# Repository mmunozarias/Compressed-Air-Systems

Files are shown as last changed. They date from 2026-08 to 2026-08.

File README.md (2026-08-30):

# Compressed-Air Systems

Work on compressed-air engines and their control, University of Groningen.

## CAE-bench

The compressed-air Wankel engine test bench: bill of materials, assembly,
wiring, calibration, firmware, control software and the 2024 measurement data.
Start at `CAE-bench/README.md`.

## compressed-air-ph-control

Port-Hamiltonian control of compressed-air engines. Simulation code for
"Energy-Based Speed Regulation of Compressed-Air Engines",
Munoz-Arias, Esquivel-Sancho and del Puerto-Flores.

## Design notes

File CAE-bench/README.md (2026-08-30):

# Compressed-Air Wankel Engine Test Bench

Everything needed to rebuild the compressed-air engine experiment used in
**Mechanical Craftsmanship & Design and Construction** at the Faculty of Science and
Engineering, University of Groningen.

A 3D-printed Wankel rotary engine runs on air from a converted fire-extinguisher
tank. A servo-driven ball valve throttles the inlet. Pressure, flow and shaft speed
are logged, and a PID loop regulates engine speed by commanding the valve.

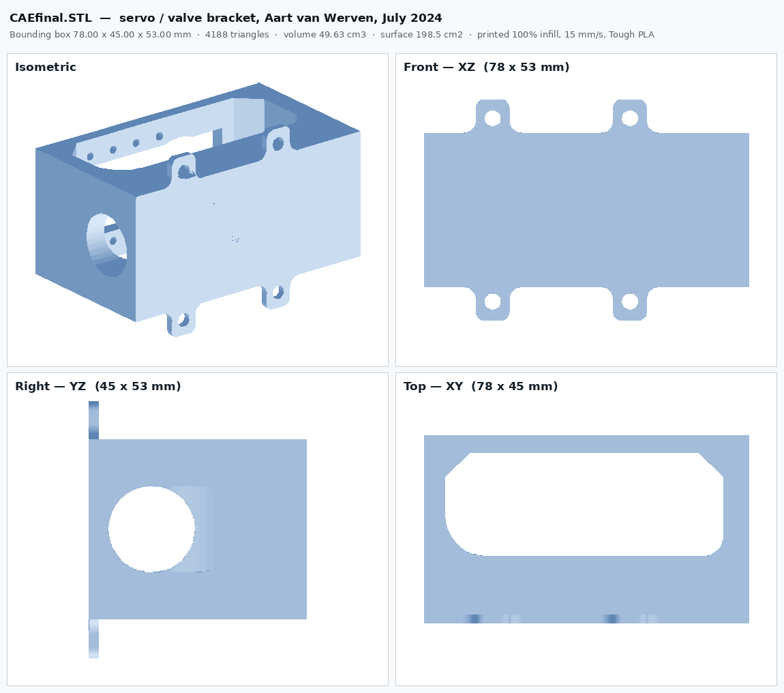
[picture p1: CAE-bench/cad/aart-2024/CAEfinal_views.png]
The servo and valve bracket


---

## Read this first

**The 2024 data in this repository is wrong by known, fixed factors.** Speed is a
factor of 4.84 too low and flow is 12.4 times too high, from a counting-window bug in
the acquisition chain. Corrected copies are in `data/processed/`, and the arithmetic
is in [`docs/07_KNOWN_ISSUES.md`](docs/07_KNOWN_ISSUES.md). **Fix defects D1 to D3
before you take a single new measurement.**

**Two gaps remain, and this repository says exactly where they are.** The three
student final reports and the original assembly-manual PDF are not here — download
links are in [`MISSING_FILES.md`](MISSING_FILES.md) §D. And five printed parts, all
of which carry an instrument, have no CAD in any archive and must be redrawn
([`MISSING_FILES.md`](MISSING_FILES.md) §E). Everything mechanical, pneumatic and
electrical that was ever drawn or flashed is in this repository.

---

## Contents

```
CAE-bench/
├── README.md                     you are here
├── MISSING_FILES.md              what to download, what to redraw, what is gone
├── CITATION.cff
├── docs/
│   ├── 01_BILL_OF_MATERIALS.md   pneumatic, mechanical, sensors, actuator, electrical
│   ├── 02_MECHANICAL_ASSEMBLY.md safety, engine build, frame, actuator, torque rig
│   ├── 03_PNEUMATIC_CIRCUIT.md   the air path, operating points, valve area curve
│   ├── 04_ELECTRONICS_AND_WIRING.md  pin map, Dynamixel chain, why 5 V
│   ├── 05_SENSORS_AND_CALIBRATION.md pressure, flow, force, speed resolution
│   ├── 06_SOFTWARE.md            install, run, control law, data format
│   └── 07_KNOWN_ISSUES.md        seven defects, the torque gap, two doc errors
├── cad/
│   ├── README.md                 measured geometry and the print profile
│   ├── aart-2024/                the servo and valve bracket (6 files)
│   ├── wankel-2023/              engine, covers, crank, shaft, pulleys (8 files)
│   │   └── Random/               design iterations and STEP exports (17 files)
│   ├── pneumatics/               sensor adapters and valve frame (5 files)
│   └── torquemeter/              the friction-brake torque rig (11 files)
├── firmware/
│   ├── arduinoADC/               the 2024 acquisition sketch
│   ├── legacy-2024/              the superseded January 2024 sketch
│   └── bench-2023/               calibration, brake and sensor-test sketches (11 files)
├── software/
│   ├── CAEPC.py                  the 2024 PC-side control loop
│   ├── requirements.txt
│   └── matlab/                   the 2023 MATLAB controller and dataset scripts
├── data/
│   ├── raw-2024/                 11 runs as logged, plus their PDF plots
│   └── processed/                the same runs with corrected columns
└── reference/
    ├── assembly_manual_2024.md
    ├── sensor_calibration_procedure_2023.md
    ├── MCDC_Sensor_calibration_procedure.pdf   the original of the above
    └── bench_purchase_record.csv
```

---

## Build it

1. **[Bill of materials](docs/01_BILL_OF_MATERIALS.md)** — order the parts. Budget
   about €300–350 plus €11 of filament for one bench. Two things to get right:
   the bearings are **R188 ZZ 6.35 × 12.7 × 4.76 mm** (the 3.18 mm version was
   superseded), and the bracket screws are **M4**, not the M2 the old report says.
2. **Print the parts.** `cad/wankel-2023/` for the engine, `cad/pneumatics/` for the
   sensor adapters, `cad/aart-2024/` for the servo bracket at 100 % infill, and
   `cad/torquemeter/` if you are building the brake. Redraw the five missing sensor
   mounts — `MISSING_FILES.md` §E lists them.
3. **[Assemble](docs/02_MECHANICAL_ASSEMBLY.md)** — engine first, and it must spin
   freely by hand before anything else is attached.
4. **[Plumb it](docs/03_PNEUMATIC_CIRCUIT.md)** — tank, adapter, pressure tee, flow
   sensor, hand valve, servo valve, engine. Leak-test at 2 bar before going to 8.
5. **[Wire it](docs/04_ELECTRONICS_AND_WIRING.md)** — pressure to A0, flow to D2,
   IR to D3. Those two digital pins are fixed by the Uno's interrupt hardware.
6. **[Calibrate](docs/05_SENSORS_AND_CALIBRATION.md)** — pressure, then flow, then
   force. Do not skip this; the shipped constants are for water.
7. **[Run it](docs/06_SOFTWARE.md)** — flash `arduinoADC.ino`, then
   `python CAEPC.py`. 60-second runs, step the hand valve open at t ≈ 10 s.

---

## Safety

The tank is a repurposed fire extinguisher. **8 bar maximum.** Eye protection
whenever it is charged. The engine reaches roughly 2700 rpm unloaded at the normal
operating point and over 7000 rpm in the high-pressure test; printed parts leaving a
rotor at that speed are dangerous. Aart van Werven's own closing note: *"running the
experiment at full force can not be considered safe, the screws in the current
connecting piece loosen due to the high vibrations and rotational force and get
launched at high speed."* Fit a guard and thread-lock the coupling screws.

---

## Provenance

Four student generations, one bench.

| Year | Who | Contribution |
|---|---|---|
| 2023 | **Koen Kiewiet** | 3D replication of the Wankel and multi-domain characterisation. BSc Integration Project. |
| 2023 | **Niek Hilbrands** | Closed-loop PID speed control and a Simscape digital twin. `Final_PID.m`, `Final_DT.slx`. |
| 2023 | **Jelmer Veenhuizen & Quentin Hopman** | Teaching assistants. The sensor calibration procedure, and the friction-brake torque rig that was never logged. |
| 2024 | **Damien Dufour** | The assembly manual and the engine technical drawings. |
| 2024 | **Aart van Werven** | Electronics rebuild: Raspberry Pi 5 + Arduino ADC, Dynamixel AX-12A, Python control loop, the servo bracket in `cad/aart-2024/`. All data in `data/raw-2024/`. |
| 2023–25 | **Max Kloosterman** | Teaching assistant and hardware custodian; later the pneumatic rover and the microscope valve-area characterisation. |

Supervised by **Mauricio Muñoz-Arias**, ENTEG, Faculty of Science and Engineering,
University of Groningen.

Upstream repository: `github.com/AartCodes/RUG-Pneumatic-Engine-experiment`
(the report cites the old username `Avuxy`).

---

## Contributing to this bench

The three things most worth doing next, in order:

1. **Fix the acquisition** (D1, D2, D4, D6). Timestamp the publish window instead of
   assuming it. This is about ten lines and it makes every future measurement valid.
2. **Wire the load cell.** The cells are bought and fitted, the friction brake is
   printed, the calibration procedure is written. One analog channel and a column in
   the Excel writer closes a gap that three student generations listed as future work.
3. **Reprint the interruptor disc with 10 lobes** instead of 3. Together with (1) this
   takes speed resolution from about 97 rpm to about 29 rpm.

A twenty-second coast-down run — spin up, close the valve, log until it stops — would
also give `b/J` for the shaft directly from the decay slope. No run in the archive
contains one, and it is the only shaft parameter measurable without a torque channel.

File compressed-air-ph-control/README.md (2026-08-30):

# Energy-Based Speed Regulation of Compressed-Air Engines

Simulation code for

> M. Munoz-Arias, L. M. Esquivel-Sancho and D. del Puerto-Flores,
> "Energy-Based Speed Regulation of Compressed-Air Engines,"
> *IEEE Transactions on Control Systems Technology* (submitted).

The scripts here regenerate **Figure 3** and **Figure 4** of the paper and print
every number quoted in Section V and Table II, so the results can be checked
without re-deriving anything.

---

## Contents

| File | What it does |
|---|---|
| `cae_model.py` | Shared parameters and dynamics, eqs. (6) to (35). Draws nothing. |
| `cae_open_loop.py` | Open-loop three-chamber simulation. Produces **Figure 3** and the Section V-A numbers. |
| `cae_closed_loop.py` | Closed-loop controller simulation, eqs. (40) to (42). Produces **Figure 4** and **Table II**. |
| `requirements.txt` | Python dependencies. |

Every function carries the equation number it implements. `cae_model.py` opens
with a table mapping each equation of the paper to the code that realises it.

Equation numbers in the source comments refer to the manuscript.

---

## Requirements

Python 3.9 or newer, with NumPy, SciPy and Matplotlib.

---

## Setup on Windows (PowerShell)

Check that Python is on the path:

```powershell
python --version
```

If that fails, install Python from <https://www.python.org/downloads/windows/>
and tick **Add python.exe to PATH** during installation.

Clone the repository and create a virtual environment inside it:

```powershell
git clone https://github.com/<user>/<repo>.git
cd <repo>
python -m venv .venv
```

Activate the environment:

```powershell
.\.venv\Scripts\Activate.ps1
```

If PowerShell refuses with a script-execution error, allow local scripts for
this session only and try again:

```powershell
Set-ExecutionPolicy -Scope Process -ExecutionPolicy Bypass
.\.venv\Scripts\Activate.ps1
```

Install the dependencies:

```powershell
python -m pip install --upgrade pip
python -m pip install -r requirements.txt
```

---

## Running

Both scripts write a vector `.pdf` for the paper and a `.png` preview into the
current directory, and print their results to the terminal.

```powershell
python cae_open_loop.py
python cae_closed_loop.py
```

Useful options:

```powershell
python cae_closed_loop.py --show              # open an interactive window
python cae_open_loop.py --outdir figures      # write into .\figures\
python cae_open_loop.py --tmax 30 --n 24000   # run length and sample count
```

To deactivate the environment when finished:

```powershell
deactivate
```

---

## What you should see

### `cae_closed_loop.py`

This reproduces Table II of the paper exactly. Expected output:

```
[baseline]  A=5.0  Kp=0.002  Kd=0.0005  Ki=0.002
   Delta(s), eq. (51) = s^3 + 10 s^2 + 65 s + 100
   eigenvalues of M   : -3.973-5.735j, -3.973+5.735j, -2.054+0j
   Routh a2a1 - a3a0  : 550.0   > 0, Hurwitz
   decay rate gamma   : 2.054 1/s

[fast]  A=12.0  Kp=0.008  Kd=0.0012  Ki=0.01
   Delta(s) = s^3 + 24 s^2 + 324 s + 1200
   eigenvalues of M   : -9.324-11.72j, -9.324+11.72j, -5.353+0j
   Routh a2a1 - a3a0  : 6576.0   > 0, Hurwitz
   decay rate gamma   : 5.353 1/s

[baseline] omega_e = 2000.1 rpm,  z = 0.0500 N m,  theta_bar = -3.69e-03 rad
[fast    ] omega_e = 2000.0 rpm,  z = 0.0500 N m,  theta_bar = -1.64e-09 rad
```

The script also checks that the eigenvalues of the closed-loop matrix `M` in
eq. (47) agree with the roots of the characteristic polynomial of eq. (49) to
machine precision, which is the numerical statement of Theorem 2.

### `cae_open_loop.py`

Four panels: tank pressure, chamber gauge pressure, pipe mass flow and shaft
speed, each for `D = 1.0` and `D = 0.5`. The engine self-starts, runs, and stops
when the tank reaches atmospheric pressure. The script prints the peak speed,
the plateau speed, the mean flow and the stopping time for each throttle
setting. Expected output:

```
D = 1.0 (fully open)
    peak shaft speed        2169.2 rpm
    plateau speed (2-5 s)    735.2 rpm
    mean flow (2-5 s)       2186.8 L/h
    engine stops at          10.13 s
D = 0.5 (half open)
    peak shaft speed        1940.8 rpm
    plateau speed (2-5 s)    750.9 rpm
    mean flow (2-5 s)       2172.7 L/h
    engine stops at          11.10 s
```

These are the numbers quoted in Section V-A. The figures the scripts write are
byte-for-byte the ones included in the manuscript.

---

## Model notes

**Geometry.** The simulations use the **measured** bench geometry,
`V_BAR = 8.25e-6` m^3 and `DELTA_V = 1.25e-5` m^3, not the reference geometry
of Table I, whose mean chamber volume of 0.1 L is about twelve times larger.
This is the scale discrepancy discussed in Section VII, and it accounts for
roughly an order of magnitude in the absolute pressure and flow amplitudes.

**Port timing.** The four port angles in `cae_model.py`
(`INTAKE_OPEN`, `INTAKE_CUTOFF`, `EXHAUST_OPEN`, `EXHAUST_CLOSE`) are not
documented for this engine and are set to physically reasonable values rather
than calibrated. The steady-speed plateau is sensitive to them. This is the
port-timing calibration gap named in Section VII, and closing it against a
measured bench trace is the first item of future work.

**Scope of the closed-loop result.** `cae_closed_loop.py` simulates the shaft
subsystem under Assumption 3, which is the setting Theorems 1 and 2 address. It
does not include the valve realisation, the one-sided throttling authority, or
the depleting tank. The commanded torque staying inside the engine envelope is
evidence that the realisability assumption is not being violated, but the full
cascade on the three-chamber plant is future work.

---

## Licence

%% TODO: choose a licence. MIT is the usual choice for code accompanying a
%% paper. Add a LICENSE file at the repository root.

## Citing

%% TODO: add the BibTeX entry for the paper once it has a DOI, and consider
%% archiving a release on Zenodo so the code itself is citable.

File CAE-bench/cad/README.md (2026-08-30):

# CAD

## What is here

`aart-2024/` — the servo and valve bracket, complete, byte-exact from Aart van
Werven's repository. This is the only subassembly whose CAD survived with its author.

| File | What |
|---|---|
| `CAEfinal.STL` | the bracket, mesh form, 4188 triangles |
| `CAE(1).SLDPRT` | SolidWorks source for the bracket |
| `CAEconnect.SLDPRT` | SolidWorks source for the servo horn |
| `UMS5_CAE8.3mf` | Cura 5.7.1 project, sliced, with the full print profile |
| `CAEfinal_views.png` | measured orthographic and isometric views |
| `UMS5_CAE8_thumbnail.png` | Cura's own render |

Both `.SLDPRT` files are post-2015 compressed SolidWorks containers. They open in
SolidWorks and nowhere else; there is no extractable preview or neutral geometry.
If you do not have SolidWorks, work from `CAEfinal.STL` and the measurements below.

## Measured geometry — CAEfinal.STL

Taken from the mesh, not from the report.

```
bounding box      78.00 x 45.00 x 53.00 mm
triangles         4188
volume            49.63 cm3 solid
surface area      198.46 cm2
mass in PLA       61.5 g at 100% infill, 1.24 g/cm3

valve bore        D 17.87 mm, axis along X
                  centre at Y 12.96, Z 26.46

mounting holes    4 x D 3.96 mm   <- M4 clearance, the report's "M2" is wrong
                  X 16.48 and 49.48   (33.00 mm apart)
                  Z  4.49 and 48.49   (44.00 mm apart)

top plate         carries the AX-12A screw pattern and the horn slot
horn screws       16 mm apart, into the AX-12A horn
```

## Print profile, recovered from the 3MF

Cura 5.7.1, UltiMaker S5, dual extrusion.

```
global            layer_height 0.2 · adhesion_type none · prime_tower True
                  support_enable True · support_structure tree
left  (AA 0.4)    Tough PLA Red · infill 100% · speed 15 mm/s · walls 5 · support infill 40%
right (BB 0.4)    PVA           · infill  70% · speed 50 mm/s · walls 5 · support infill 10%
print time        17 h 42
```

**The part is on the left extruder.** Table II of the 2024 report quotes the right
extruder's numbers (70 % / 50 mm/s), which describe the PVA support, not the part.
Print at 100 % infill; this bracket takes the servo reaction torque.

## What is not here

`wankel-2023/`, `pneumatics/` and `torquemeter/` are empty placeholders. Those files
are binary and could not be pulled programmatically. Every download link is in
`MISSING_FILES.md` section C.

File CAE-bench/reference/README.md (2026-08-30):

# Reference documents

Primary sources, transcribed. The originals are linked in `MISSING_FILES.md` §B and
§C6 — download them, because the drawings and figures do not survive transcription.

| File | Original | Author, date |
|---|---|---|
| `assembly_manual_2024.md` | `Compressed_air_engine_assembly_manual (4).pdf` | Damien Dufour, 6 Feb 2024 |
| `sensor_calibration_procedure_2023.md` | `MCDC_Sensor_calibration_procedure (1).pdf` | Jelmer Veenhuizen & Quentin Hopman, 6 Nov 2023 |
| `bench_purchase_record.csv` | `BoM_experimentalSetup_MCDC.xlsx` | MCDC teaching team, 2023-24 |

**The assembly manual contains technical drawings that are not reproduced here** —
dimensioned drawings for the Wankel mainframe, top cover and rotor, plus the full
piston and turbine engine variants. Download the PDF if you need them.

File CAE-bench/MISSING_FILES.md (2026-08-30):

# Files still to fetch, and files that no longer exist

Updated 30 August 2026, after the manual Drive download.

**The CAD and 2023 firmware gaps are closed.** Four of the five folders that were
empty are now populated: `cad/wankel-2023/`, `cad/pneumatics/`, `cad/torquemeter/`
and `firmware/bench-2023/`. What remains below is a short list.

---

## A. Byte-exact, in the repository

### A1. From `github.com/AartCodes/RUG-Pneumatic-Engine-experiment` @ `270cbc5`

- `firmware/arduinoADC/arduinoADC.ino`
- `firmware/legacy-2024/CEA_OLD_Jan_2024.ino`
- `software/CAEPC.py`, `software/matlab/baip_old.m`
- `cad/aart-2024/` — all four CAD files
- `data/raw-2024/` — all 11 run workbooks and their PDF plots
- `CITATION.cff`

### A2. Downloaded by hand from Google Drive, 30 August 2026

| Folder | Count | Contents |
|---|---|---|
| `cad/wankel-2023/` | 8 + 17 | Engine assembly, mainframe, top cover, rotor, crank, output shaft, two GT2 pulleys; `Random/` holds the design iterations and STEP exports |
| `cad/pneumatics/` | 5 | Sensor adapters, flow-valve frame and adapter |
| `cad/torquemeter/` | 11 | **The complete friction-brake torque rig** — bases, three brake rotors, two friction elements, holder, coupling stabiliser, engine mounting base, and the Cura 3MF |
| `firmware/bench-2023/` | 11 | Calibration sketches, three brake firmwares, the demo sketch, sensor test sketches (three non-firmware files were refiled — §B2) |

---

## B. Three files that arrived and were not on any list

Worth knowing about — none of these appeared in the original sweep.

| File | Where it landed | Why it matters |
|---|---|---|
| `Final_PID.m` | now `software/matlab/` | **The byte-exact original** of the 2023 controller. The repository previously held only the text-recovered copy. Verified — see §B1. |
| `NewDatasetPQN.m` | now `software/matlab/` | A MATLAB pressure/flow/speed dataset script that accompanied the January 2024 demo. Not referenced in any report. |
| `braccioServoTestwithoutShield.ino`, `pressure_sensor.ino`, `water_flow_sensor.ino` | `firmware/bench-2023/` | Single-sensor test sketches. The two sensor ones are the cleanest reference for the raw pin reads. |

### B1. The diff was run, and it passed

`software/matlab/Final_PID_2023_RECOVERED.m` was reconstructed from a
markdown-escaped API rendering. On 30 August 2026 it was compared line by line
against the original. **No numeric literal and no operator differs.** `Kp`, `Ki`,
`Kd`, `desiredRPM`, the event-based `RPM = 60/elapsedTime`, the `(flow/11)*60`
scaling and the `min(45, Angle)` clamp are all identical.

The only differences were whitespace, a provenance header added during recovery, one
comment shortened, and one typo in Hilbrands' comments silently corrected
(`%Filering` to `% Filtering`). Every conclusion in `docs/07_KNOWN_ISSUES.md` that
was drawn from the recovered file therefore holds against the original.

The recovered copy has been deleted. `software/matlab/Final_PID.m` is the original.

### B2. Three misfiled files were moved — done

They arrived inside the firmware zip but are not firmware. All three are now in place:

| File | Now at |
|---|---|
| `MCDC_Sensor_calibration_procedure.pdf` | `reference/` — the byte-exact original of `reference/sensor_calibration_procedure_2023.md` |
| `Final_PID.m` | `software/matlab/` |
| `NewDatasetPQN.m` | `software/matlab/` |

---

## C. Recovered as text, and therefore NOT byte-exact

The Google Drive API returns text files as a markdown-escaped rendering. These were
mechanically un-escaped. Two of the four now have their originals in the repository.

| File in this repo | Original | Status |
|---|---|---|
| `software/matlab/Final_PID_2023_RECOVERED.m` | — | **Verified against the original, then deleted. See §B1.** |
| `reference/sensor_calibration_procedure_2023.md` | `reference/MCDC_Sensor_calibration_procedure.pdf` | Original PDF is in the repository |
| `reference/assembly_manual_2024.md` | https://drive.google.com/file/d/12QYhJ9bgo3Mi30Q98cJiB5EE-rjmYTcK/view | still text-only, **unverified** |
| `reference/bench_purchase_record.csv` | https://drive.google.com/file/d/12S-FDaBVhX_Im-J83x53LmS7h7cCgfUk/view | still text-only, **unverified** |

---

## D. Still to download

Short list. Everything else on the old list arrived.

### D1. One STL, one adapter

| File | Into | Link | Note |
|---|---|---|---|
| `crank rotary_full_thread.STL` | `cad/wankel-2023/` | https://drive.google.com/file/d/1MkxhRA-5ii5pRoACFyRBst1Ptty3XrNf/view | `crank rotary_full_thread.STEP` and `…1.SLDPRT` did arrive, in `Random/`. Only the print-ready mesh is absent. |
| `g78p14_to_g18p28_ASPART.STL` | `cad/pneumatics/` | Drive folder "Adaptors & Connectors" | G7/8-1/4 to G1/8-1/4 thread adapter |

### D2. Two firmware variants

| File | Into | Link |
|---|---|---|
| `calibration_pressureNEW.ino` | `firmware/bench-2023/` | https://drive.google.com/file/d/10WHNEVndiqODSPl31ZAOfcYgzPOO-sFT/view |
| `Cal_flow1.ino` | `firmware/bench-2023/` | https://drive.google.com/file/d/1XcnWjRBtoMcRpctCfh-zhMIp4V-T_4Xi/view |

Both are variants of sketches that already arrived. Low priority.

### D3. Reference documents, into `reference/`

The largest remaining gap, and the one that matters most for a stranger trying to
rebuild the bench — the three final reports contain the reasoning behind the design.

| File | Link |
|---|---|
| `Compressed_air_engine_assembly_manual (4).pdf` — with all technical drawings | https://drive.google.com/file/d/12QYhJ9bgo3Mi30Q98cJiB5EE-rjmYTcK/view |
| `BoM_experimentalSetup_MCDC.xlsx` | https://drive.google.com/file/d/12S-FDaBVhX_Im-J83x53LmS7h7cCgfUk/view |
| `Final report - Aart van Werven.pdf` | https://drive.google.com/file/d/1jeOsAo6GKKWHYmRFczAijTgDJKLy9ffv/view |
| `Koen Kiewiet - Final Report.pdf` | https://drive.google.com/file/d/19jPMe1Uf--jlzvOY9KKocOAmeYLkY6l5/view |
| `Niek Hilbrands - Final Report.pdf` | https://drive.google.com/file/d/19nG8YkGtTjL5F2W3YVkus5UZwvXdnWn0/view |
| `CAE_drawing3.pdf`, `CAE.SLDPRT`, `CAE.SLDDRW` — **the dimensioned 2D drawing** | Gmail, 6 May 2024, message `18f4c5735a05912d` |
| Purchase orders, ~90 PDFs | https://drive.google.com/drive/folders/15pth04qXh3LmkRtO3BiwIH30W6IG_41J |

Check the licence position on the student reports before pushing them to a public
repository.

---

## E. Does not exist anywhere — must be redrawn

Five printed parts appear in the bill of materials with no CAD in any archive,
including the folders downloaded on 30 August 2026. All five carry an instrument.

| Part | Qty | What it does |
|---|---|---|
| **IR-sensor interruptor disc** | 1 | 3-lobe disc on the output shaft. **Redraw with 10 lobes** — see `docs/07_KNOWN_ISSUES.md` D1. |
| **IR-sensor holder** | 1 | positions the photo interrupter over the disc |
| **Load-cell attachment** | 2 | mounts the load cell to the brake arm. Without it the torque channel cannot be rebuilt. |
| **Sensor holder** | 1 | holds the pressure and flow sensors to the plank |
| **Tube holder** | 4 | routes the 8 mm line |

The load-cell attachment is now the **only** thing standing between this bench and a
working torque channel. Every other part of the rig — the brake, the rotors, the
friction elements, the coupling, and `calibration_force.ino` — is in this repository.

---

## F. Corrupt

`Engine_mount_wankel.STL` appears twice in the shared drive at **zero bytes**, ids
`1t633eYdxz7QXZYz_nJCpnm2AZ7vxKtjh` and `13ULi0r8Ysf9A_df54gEAvZRMN9DEu9cy`. Both
copies are unrecoverable. Use `cad/torquemeter/Engine mounting base.stl` instead —
it is now in the repository.

`cad/wankel-2023/Random/rotorstepje.err` is a SolidWorks export error log, not a
model. It is kept because it records a failed STEP translation of the rotor.

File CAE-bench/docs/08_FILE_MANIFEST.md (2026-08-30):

# 8 — File manifest

Every file in this repository, where it came from, and how much to trust it.

Legend — **A** byte-exact from Aart's GitHub repository · **B** recovered as text
through the Drive API and mechanically un-escaped, verify before relying on it ·
**C** generated during the August 2026 audit · **E** downloaded by hand from Google
Drive on 30 August 2026, byte-exact · **D** placeholder, download still required.

| Path | Src | Bytes | What it is |
|---|---|---|---|
| `README.md` | C | — | Entry point |
| `MISSING_FILES.md` | C | — | Download list, redraw list, corrupt list |
| `CITATION.cff` | A | 700 | Aart's citation metadata |
| **docs/** | | | |
| `01_BILL_OF_MATERIALS.md` | C | — | Merged from the TA bench BOM and Aart's Appendix A |
| `02_MECHANICAL_ASSEMBLY.md` | C | — | From the 2024 assembly manual plus the CAD measurements |
| `03_PNEUMATIC_CIRCUIT.md` | C | — | Air path, operating points, valve area curve |
| `04_ELECTRONICS_AND_WIRING.md` | C | — | Pin map read out of the firmware |
| `05_SENSORS_AND_CALIBRATION.md` | C | — | From the Veenhuizen & Hopman procedure |
| `06_SOFTWARE.md` | C | — | Install, run, control law, data format |
| `07_KNOWN_ISSUES.md` | C | — | Seven defects, the torque gap, two doc errors |
| `08_FILE_MANIFEST.md` | C | — | This file |
| **cad/aart-2024/** | | | |
| `CAEfinal.STL` | A | 209 484 | Servo/valve bracket, 4188 triangles |
| `CAE(1).SLDPRT` | A | 338 482 | SolidWorks source, bracket |
| `CAEconnect.SLDPRT` | A | 98 441 | SolidWorks source, servo horn |
| `UMS5_CAE8.3mf` | A | 196 921 | Cura 5.7.1 project with the full print profile |
| `CAEfinal_views.png` | C | 37 899 | Measured orthographic and isometric views |
| `UMS5_CAE8_thumbnail.png` | C | 29 731 | Extracted from the 3MF |
| `README.md` | C | — | Measured geometry and print settings |
| **cad/wankel-2023/** | E | — | 8 files: `Wankel assembly.SLDASM`, mainframe, top cover, `rotor.step.SLDPRT`, `crank rotary.SLDPRT`, `outputshaft wankel redesigned.stl`, two GT2 pulleys |
| `cad/wankel-2023/Random/` | E | — | 17 files: Casing/Lid/Rotor/Shaft 1-8 iterations, STEP exports, `crank rotary_full_thread`, `rotorstepje.err` |
| **cad/pneumatics/** | E | — | 5 files: two sensor adapters, tube-to-flow-sensor connector, `frame_flowvalve.stl`, `frame_updated.stl` (use this one) |
| **cad/torquemeter/** | E | — | 11 files: the complete friction brake. `Engine mounting base.stl` replaces the corrupt `Engine_mount_wankel.STL` |
| **firmware/** | | | |
| `arduinoADC/arduinoADC.ino` | A | 3 100 | 2024 acquisition sketch. JSON over serial at 19200 |
| `legacy-2024/CEA_OLD_Jan_2024.ino` | A | — | The superseded January 2024 sketch |
| `bench-2023/torquemotor1–3.ino` | E | — | The three brake firmwares. Never used in any report |
| `bench-2023/calibration codes/` | E | — | `calibration_pressure`, `calibration_flow`, **`calibration_force`** — the load-cell sketch |
| `reference/MCDC_Sensor_calibration_procedure.pdf` | E | 167 479 | The original calibration procedure, Veenhuizen & Hopman |
| `bench-2023/CEA_Demo_22_Jan_2024/` | E | — | The January 2024 live-demo sketch |
| `bench-2023/pressure_sensor/`, `water_flow_sensor/`, `flow_pressure_combined/`, `braccioServoTestwithoutShield/` | E | — | Single-sensor and servo test sketches |
| **software/** | | | |
| `CAEPC.py` | A | 14 056 | 2024 PC-side control loop, Dynamixel + matplotlib + xlsx |
| `requirements.txt` | C | — | Reconstructed from the imports; not in the original repo |
| `matlab/baip_old.m` | A | 8 600 | Marked outdated in the original repository |
| `matlab/Final_PID.m` | E | 8 539 | Hilbrands' 2023 controller, byte-exact original. The recovered copy was verified against it and deleted — MISSING_FILES.md §B1 |
| `matlab/NewDatasetPQN.m` | E | 6 052 | Pressure/flow/speed dataset script, January 2024 demo |
| **data/raw-2024/** | | | |
| `DATACAE.xlsx` … `ResultNoPID2.xlsx` (11 files) | A | ~40 kB each | The runs as logged. **Speed ×4.84 too low, flow ×12.4 too high.** |
| `*.pdf` (10 files) | A | — | The plots as generated at run time |
| `experiment_data.pdf` | A | — | Combined plot export |
| **data/processed/** | | | |
| `CAE_bench_corrected_data.xlsx` | C | — | All 11 runs with corrected columns, driven by formula from one correction sheet |
| **reference/** | | | |
| `assembly_manual_2024.md` | **B** | — | Dufour, 6 Feb 2024. Technical drawings NOT reproduced |
| `sensor_calibration_procedure_2023.md` | **B** | — | Veenhuizen & Hopman, 6 Nov 2023 |
| `bench_purchase_record.csv` | **B** | — | The compressed-air rows of the MCDC purchase record |
| `README.md` | C | — | Source table for the above |

## Verifying the B files

```powershell
# after downloading the original from the link in MISSING_FILES.md
git diff --no-index original.m software/matlab/Final_PID_2023_RECOVERED.m
```

Expect differences in whitespace and in the header comment block, which was added.
Any difference in a numeric literal or an operator is a transcription error — fix it
and note it here.

## Suggested .gitignore

```
__pycache__/
*.pyc
.venv/
*.tmp
~$*
```

Everything else in this tree is meant to be committed, including the data.

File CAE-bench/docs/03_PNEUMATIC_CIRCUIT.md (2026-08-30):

# 3 — Pneumatic circuit

## 3.1 The line, in order

```
  [ Fire extinguisher tank, 8 bar max ]
              |
              |  G7/8-14 outlet
        ( P2 ) printed adapter  g78p14_to_g18p28_ASPART.STL   -> G1/8
              |
        ( P4 ) PC8-01 straight fitting, 1/8 BSP -> 8 mm push-fit
              |
        ( P3 ) 8 mm OD / 5 mm ID PU hose
              |
        ( P6 ) G1/8 T-split ----------------> ( S2 ) PRESSURE SENSOR
              |                                     G1/4, 0-100 psi, analog
              |
        ( S1 ) FLOW SENSOR, SENSTREE G1/2
              |    via printed adapters S5
              |
        ( P8 ) HAND BALL VALVE   <- master isolation, operator controlled
              |
        ( P9 ) SERVO BALL VALVE  <- THE CONTROL ELEMENT, driven by the AX-12A
              |                     mounted in CAEfinal.STL
              |
        [ WANKEL ENGINE inlet port ]
              |
        exhaust to atmosphere
              |
      output shaft --> ( S3 ) IR PHOTO INTERRUPTER (speed)
                   --> optional brake + load cell (torque)
```

## 3.2 Notes that are easy to get wrong

**The pressure sensor reads line pressure, not tank pressure.** In the 2024 data the
open-loop runs peak at only 2.4-2.6 bar while the closed-loop runs reach 6.1-7.4 bar,
from the same tank charge. That is the pressure drop across the flow sensor and tubing
at high flow. If you want true tank pressure, tee the sensor in *before* the flow
sensor, or fit a second transducer.

**Keep the bends out of the 8 mm line.** The bracket was designed to raise the tube
height by only 1 mm precisely to avoid this. Every bend costs flow.

**Seal the printed adapters with O-rings, not tape.** The O-ring set (P10) was bought
for this. PTFE tape on a printed thread tends to shred.

**Leak test before every session.** Aart's predecessors lost measurement days to
leaks. Soap water at 2 bar, then work up.

## 3.3 Operating points on record

| Condition | Tank / line pressure | Speed (corrected) | Flow (corrected) |
|---|---|---|---|
| Open loop, valve wide | 2.4-2.6 bar at the sensor | 2655-3038 rpm plateau | ~2540-2700 L/h |
| Closed loop, setpoint 200 logged | 5.0-5.3 bar at the sensor | ~960 rpm | ~250-475 L/h |
| High-pressure limit test | 10.1 bar peak | up to ~7700 rpm peak | ~4700 L/h peak |

All speeds and flows above are **corrected** figures. The raw logs are wrong by fixed
factors; see `docs/06_KNOWN_ISSUES.md` before using any number from `data/raw-2024/`.

## 3.4 Valve angle and flow area

The throttle is a quarter-turn ball valve. Its flow area is **not** linear in angle:
it is the overlap of two circular apertures. Max Kloosterman measured a valve of the
same family through a microscope in 2 .5 degree steps:

| Rotation from fully open | Aperture, % of maximum |
|---|---|
| 0 deg | 100 % |
| 10 deg | 79 % |
| 20 deg | 57 % |
| 30 deg | 33 % |
| **40 deg** | **17 %** |
| **50 deg** | **5.7 %** |
| 55 deg | 1.5 % |

The pure two-circle geometry over-predicts badly (46 % where the real valve is 3 %
open). The empirical fit that works is the lens area multiplied by (1 - theta/60 deg).

**Consequence for control:** the 2024 bench settles at 43-44 degrees from open, which
is about **13 % of maximum aperture** — on the steep part of the curve, with almost no
margin before the engine stalls. Any controller for this rig should command *area*,
not angle, and invert this curve. That is what the 2025 rover firmware does.

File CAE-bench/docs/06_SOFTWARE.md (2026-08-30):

# 6 — Software

Two generations. Build the 2024 one; the 2023 MATLAB is included because it is
correct in ways the 2024 rewrite is not.

---

## 6.1 What runs where

| Layer | 2023 | 2024 (this repo) |
|---|---|---|
| Sensor acquisition | `CEA_OLD_Jan_2024.ino` on an Arduino Uno | `arduinoADC.ino` on an Arduino Uno |
| Wire format | CSV over serial, 19200 baud | **JSON lines** over serial, 19200 baud |
| Control loop | MATLAB, `Final_PID.m` | Python, `CAEPC.py` |
| Actuator | SpringRC SR431 via Arduino | Dynamixel AX-12A via U2D2 from the PC |
| Output | live MATLAB plots | live matplotlib + PDF + `.xlsx` |

---

## 6.2 Install

```powershell
# 1. Python 3.9 or newer, and the Arduino IDE
python --version

# 2. Python packages
python -m pip install -r software/requirements.txt

# 3. Flash the Arduino
#    Open firmware/arduinoADC/arduinoADC.ino in the Arduino IDE.
#    Install the ArduinoJson library via Library Manager.
#    Select Arduino Uno, pick the port, Upload.

# 4. Find your COM ports
#    Device Manager for the Arduino; Dynamixel Wizard for the servo.
#    Then edit software/CAEPC.py:
#        DEVICENAME = 'COM8'      <- the U2D2
#        ser = serial.Serial('COM6', 19200, timeout=0.1)   <- the Arduino
```

`software/requirements.txt` is reconstructed from the imports in `CAEPC.py`; it was
not in the original repository.

---

## 6.3 Run

```powershell
cd software
python CAEPC.py
```

The loop runs for **60 seconds** and then stops itself. It writes two files to your
Desktop:

- `experiment_data.pdf` — the four plots plus a text page of the raw arrays
- `DATACAE.xlsx` — columns `Time (s)`, `RPM`, `Pressure (Bar)`, `Flow Rate (L/m)`,
  `Servo Position`

Rename `DATACAE.xlsx` immediately after each run or the next run overwrites it. This
is how the 11 files in `data/raw-2024/` came to have ad-hoc names.

**Procedure for a run.** Start the script with the hand valve closed. At about
t = 10 s open the hand valve — this is the step input. The controller takes roughly
6 s to settle. Let it run to 60 s.

---

## 6.4 The control law as shipped

```python
class PID:
    def compute(self, setpoint, pv):
        error = setpoint - pv
        self.integral += error
        derivative = error - self.previous_error
        output = self.Kp*error + self.Ki*self.integral + self.Kd*derivative
        self.previous_error = error
        return output

pid = PID(0.1, 0.02, 0.0003)
Desired_Speed = 210          # was 200 for every run in data/raw-2024

servo_position = 200 + ((512 - 200) * pid_output / Desired_Speed)
```

Four things to know before you tune it. All four are expanded in
`docs/07_KNOWN_ISSUES.md`.

1. There is **no timestep** in the integral or derivative. The gains are per-sample,
   so they change if the loop rate changes.
2. There is **no anti-windup**. `set_servo_position` clamps to 200-512 while the
   integral keeps accumulating.
3. **The setpoint divides the actuator gain.** Loop gain at a setpoint of 100 is
   double that at 200 and four times that at 400. Retuning per setpoint is treating a
   symptom.
4. The **derivative term is inert** — with 20-unit speed quantisation and
   Kd = 0.0003 it contributes 0.006 servo units against a 0.5-unit deadband. This is
   a PI controller.

---

## 6.5 The 2023 MATLAB controller

`software/matlab/Final_PID_2023_RECOVERED.m`. Gains `Kp = -0.003`, `Ki = 0.0002`,
`Kd = -0.003`, setpoint **1500 rpm**, angle clamped to **0-45 degrees**.

Two things it does better than the 2024 rewrite:

- **Speed is event-based and correct.** It times one full revolution with `tic`/`toc`
  and computes `RPM = 60/elapsedTime`. No window assumption, no scale error.
- **Flow is labelled L/hour**, which matches the arithmetic.

It also does outlier rejection with a 10-sample moving mean on speed, pressure and
flow, which the Python rewrite dropped.

`software/matlab/baip_old.m` is the earlier MATLAB the repository marks as outdated.

---

## 6.6 Data format

`data/raw-2024/*.xlsx`, 11 runs, ~284 rows each:

| Column | Unit as labelled | Trust it? |
|---|---|---|
| `Time (s)` | s | Frame time, not sample time. Up to 3 samples share one stamp. |
| `RPM` | rpm | **No — multiply by 4.84** |
| `Pressure (Bar)` | bar absolute | Yes |
| `Flow Rate (L/m)` | L/min | **No — divide by 12.4 for L/min** |
| `Servo Position` | Dynamixel units, 200-512 | Yes |

`data/processed/CAE_bench_corrected_data.xlsx` has every run with corrected columns
driven by formula off a single correction sheet, so editing the measured emission rate
rescales the whole workbook.

Run-to-test mapping, verified by reproducing the report's own error metric:

| File | Setpoint | Role |
|---|---|---|
| `Result31` | 200 | Test 1 |
| `Result32` | 200 | Test 2 |
| `Result33` | 200 | Test 3 |
| `Result34` | 200 | Test 4 |
| `Result11` | 200 | Test 5 |
| `ResultNoPID`, `ResultNoPID2` | 200 | open-loop baselines |
| `Result10bar` | 200 | high-pressure limit test |
| `Result100` | 100 | low-setpoint test |
| `Result400` | 400 | high-setpoint test |
| `DATACAE` | 200 | unreported spare |

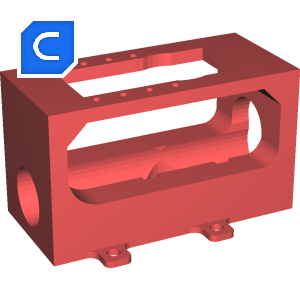
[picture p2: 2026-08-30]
CAE-bench/cad/aart-2024/UMS5_CAE8_thumbnail.png

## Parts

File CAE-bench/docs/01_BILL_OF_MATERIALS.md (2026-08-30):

# 1 — Bill of materials

Everything needed to build one compressed-air Wankel engine test bench, split by
discipline. Two sources are merged here: the **TA bench BOM** from
`BoM_experimentalSetup_MCDC.xlsx` (the setup as actually built, with quantities and
unit costs) and **Appendix A of Aart van Werven's 2024 report** (the setup after the
electronics rebuild). Where they disagree, both are shown.

Prices are as paid, 2023–24, in EUR unless the source quoted USD.

---

## 1.1 Pneumatic parts

| # | Part | Spec | Qty | Unit | Notes |
|---|---|---|-----|---|---|
| P1 | Air tank | Smartwares 10.014.68 ABC powder fire extinguisher, 2 kg — tank only, contents removed | 1 | €36.99 | This is the "pneumatic battery". A 1 kg version (10.018.56, €29.00) was also used. Maximum working pressure 8 bar in this application. |
| P2 | Tank outlet adapter | 3D printed, G7/8-14 to G1/8-28 | 1 | printed | `g78p14_to_g18p28_ASPART.STL`. Threads onto the extinguisher valve body. |
| P3 | Pneumatic tubing | HUAZIZ PU hose, 8 mm OD / 5 mm ID, blue | ~70 cm | €15.66 / 12 m | 10–12 m rolls were bought; a bench needs under a metre. |
| P4 | Straight push-fit fittings | TAILONZ PC8-01, 8 mm tube OD × 1/8 BSP male | 6–10 | €9.99 / 10 | The workhorse fitting of the whole rig. |
| P5 | Elbow push-fit fittings | TAILONZ male elbow, 8 mm OD × 1/8 BSP | 2–4 | €13.49 | For routing around the plank. |
| P6 | T-split | G1/8 pneumatic T-piece, or IQS R1/4 to 8 mm tee | 1 | €38.72 / set | Splits the line to the pressure sensor. |
| P7 | Quick connectors | 8 mm to 1/4 BSP adapters | 2 | €9.99 / 10 | Compressor side. |
| P8 | Hand shut-off valve | TAILONZ BVU-8, 8 mm OD ball valve, push-to-connect | 1 | €18.99 | Master isolation. Always fit one. |
| P9 | **Throttle valve (the actuator)** | TAILONZ BVU-8 8 mm OD ball valve — a second unit, driven by the servo | 1 | €9.99 | This is the control element. See §1.5 and `docs/03_PNEUMATIC_CIRCUIT.md`. |
| P10 | O-ring set | NBR, 32 sizes, 419 pieces | 1 set | €17.45 | Sealing the printed adapters. Sizes 1 and 2 in the TA BOM, ×2 and ×4. |
| P11 | Compressor | HBM, with 5-piece air tool set for the hose and couplings | 1 | €26.90 (accessories) | Any 8 bar workshop compressor. |

> **Safety.** The tank is a repurposed fire extinguisher. Do not exceed **8 bar**.
> Wear eye protection whenever the tank is charged. See §1 of the assembly manual
> in `reference/`.

---

## 1.2 Mechanical parts — the engine

The Wankel is fully 3D printed apart from bearings and fasteners.

| # | Part | Spec | Qty | Source |
|---|---|---|-----|---|
| M1 | Base cover / mainframe | PLA, printed | 1 | `Wankel mainframe.stl` |
| M2 | Top cover | PLA, printed | 1 | `Wankel topcover.stl` |
| M3 | Rotor | PLA, printed | 1 | `rotor.step.SLDPRT` |
| M4 | Crank / eccentric shaft | PLA, printed | 1 | `crank rotary.SLDPRT`, or `crank rotary_full_thread.STL` |
| M5 | Output shaft | PLA, printed | 1 | `outputshaft wankel redesigned.stl` |
| M6 | Bearing A — small | **IBB R188 ZZ, 6.35 × 12.7 × 4.76 mm** | 2 | Lagerkoning.nl, €82.45 / pack |
| M7 | Bearing B — large | IBB 6802 / 61802 2RS, 15 × 24 × 5 mm | 1 | Lagerkoning.nl, €32.28 |
| M8 | Apex seals | Graphite stick, 15 mm lengths, filed flush | 3 | STAEDTLER Mars Micro 1.3 mm HB, €7.67 |
| M9 | Super glue | any cyanoacrylate | 1 | €11.99 / 18 |
| M10 | Cover screws | **M3 × 12** | 6 | with M3 square nuts |
| M11 | Cover nuts | M3 DIN557 square nuts, SS304 | 6 | €6.10 / 100 |

> **Bearing substitution, February 2024.** The original spec was IBB R188
> 6.35 × 12.7 × **3.18** mm. It was replaced by **R188 ZZ 6.35 × 12.7 × 4.76 mm**.
> The 4.76 mm width is what is on the bench now. Ordering the 3.18 mm part will not fit.

---

## 1.3 Mechanical parts — the bench frame

| # | Part | Spec | Qty | Unit |
|---|---|---|-----|---|
| F1 | Base plank | wood, 30 × 40 cm | 1 | €5.25 |
| F2 | Corner bracket | Alberts 330330, heavy, zinc | 1 | €15.13 |
| F3 | M5 threaded rod | for the load arm / mounting | 1 | €5.48 |
| F4 | M5 nuts | Jeboler DIN 985 nylon-insert lock nuts, A2 | 2 | €12.52 / 100 |
| F5 | Wood screws | 3 × 12 T10 | 19 | €7.79 / 200 |
| F6 | Bracket mounting screws | **M4** — see the warning below | 4 | — |
| F7 | 5 mm bearing | for the output shaft support | 2 | €9.56 / 20 |
| F8 | Flexible shaft coupling | OKFLEX | 1 | €24.15 |
| F9 | Tank holder | supplied with the extinguisher | 1 | included |
| F10 | Arduino holder | supplied with the board | 1 | included |
| F11 | Tube holders | printed | 4 | **no CAD survives** |

> **M4, not M2.** Aart's report §IV-D-1 says the servo bracket is secured with
> "4 4-m2-screws". The holes in `CAEfinal.STL` measure **Ø3.96 mm**, which is M4
> clearance. Buy M4.

---

## 1.4 Sensors

| # | Sensor | Spec | Qty | Unit | Interface |
|---|---|---|-----|---|---|
| S1 | Flow | **SENSTREE G1/2 brass water flow sensor** | 1 | €16.11 | Digital pulse, 5 V. Pulse-per-litre constant 11 for water (see the calibration note). |
| S2 | Pressure | **G1/4 pressure transducer, 5 V in, 0.5–4.5 V out, 0–100 psi** | 1 | €19.07 | Analog. |
| S3 | Speed | **SHARP GP1A57HRJ00F photo interrupter** + SparkFun breakout | 1 | €16.85 + €5.85 | Digital, interrupt-driven. |
| S4 | Torque / force | **Load cell 500 g** (B0CJ93Y21V, €18.33) and **1 kg** (HALJIA, €7.99 ×2), plus a 100 g unit (€10.60) | 1–2 | — | Needs an **HX711** amplifier (ICQUANZX, €6.99). *Bought and fitted; never wired into the data acquisition. See `docs/06_KNOWN_ISSUES.md`.* |
| S5 | Sensor adapters | printed: G1/4-to-flowsensor, flow/pressure-to-G1/4 | 1 each | printed | `adapter pneumatic flow pressure sensor v2.stl`, `connector tube to flow sensor 1_8 v1.stl` |
| S6 | Sensor holder, IR holder, IR interruptor disc | printed | 1 each | printed | **no CAD survives — must be redesigned** |

> **The flow sensor is a water turbine used on air.** Its 11 pulses/litre constant
> does not transfer to a compressible fluid. Treat all flow readings as indicative
> until the sensor is calibrated against a known air flow. The 2023 team calibrated
> it by the choked-flow method; see `docs/04_SENSORS_AND_CALIBRATION.md`.

---

## 1.5 Actuator

Two generations exist. Build the 2024 one.

| Generation | Servo | Stall torque | Notes |
|---|---|---|---|
| 2023 | SpringRC **SR431** (from the Braccio arm kit) | 1.22 N·m @ 4.8 V, 1.45 N·m @ 6.0 V | Imprecise, vibrates at high flow, prone to failure. Replaced. |
| **2024 (build this)** | **DYNAMIXEL AX-12A** | **1.5 N·m @ 12 V** | €19.07. TTL protocol 1, ID 0, baud 1 000 000. |

The AX-12A needs three more items, all Reichelt:

| # | Part | Unit |
|---|---|---|
| A1 | DYNAMIXEL **U2D2** USB-to-TTL interface | €56.62 |
| A2 | **U2S2 PHB** Dynamixel U2D2 Power Hub | €40.62 |
| A3 | **SMPS 12 V 5 A** Dynamixel power adapter | €46.72 |

Plus two printed parts: the **valve + motor holder** (`CAEfinal.STL`) and the **horn**
that couples the servo output to the valve stem (`CAEconnect.SLDPRT`), screwed into
the AX-12A horn at two holes 16 mm apart.

---

## 1.6 Electrical and control

| # | Part | Spec | Qty | Unit |
|---|---|---|-----|---|
| E1 | Microcontroller | **Arduino Uno Rev 3** | 1 | €26.50 |
| E2 | Host computer | Any Windows/Linux PC. A **Raspberry Pi 5** was used in 2024 but Aart's own conclusion is that it "proved to be unnecessary, since the same functionality is achieved by running the code on a laptop or PC". | 1 | — |
| E3 | Breadboard | AZDelivery mini, 400 pin | 1 | €3.99 |
| E4 | Jumper wires | male/female sets, flexible | 1 set | €16.20 |
| E5 | Crimping tool + Dupont connectors | Homca SN-28B, 2030 connectors | 1 | €38.99 |
| E6 | 9 V battery clip to 2.1 mm DC jack | for standalone power | 1 | €10.75 |
| E7 | HX711 load-cell amplifier | ICQUANZX breakout | 1 | €6.99 |
| E8 | PVC insulation tape | | 1 | — |

---

## 1.7 Consumables and tooling

| Item | Spec |
|---|---|
| Filament, part | **UltiMaker Tough PLA, red** |
| Filament, support | **UltiMaker PVA** (water soluble) |
| Printer | UltiMaker S5 (S3 / S7 also used), AA 0.4 and BB 0.4 cores |
| Sandpaper | 120 grit, for the piston and turbine variants |
| Magnetic bit holder | 60 mm, 1/4" |
| Graphite | see M8 |

---

## 1.8 Complete printed-part list

| Part | Qty | CAD available? | File |
|---|-----|---|---|
| Wankel housing / mainframe | 1 (4 printed per cohort) | yes | `Wankel mainframe.stl` |
| Wankel top cover | 1 | yes | `Wankel topcover.stl` |
| Rotor | 1 | yes | `rotor.step.SLDPRT` + 8 iterations |
| Crank / eccentric | 1 | yes | `crank rotary.SLDPRT` |
| Output shaft | 1 | yes | `outputshaft wankel redesigned.stl` |
| Wankel frame | 1 | yes | `mainframe_wankel.step` |
| Valve + motor holder | 1 | **yes, in this repo** | `cad/aart-2024/CAEfinal.STL` |
| Servo horn / coupler | 1 | **yes, in this repo** | `cad/aart-2024/CAEconnect.SLDPRT` |
| Fire extinguisher adapter | 1 | probable | `g78p14_to_g18p28_ASPART.STL` |
| G1/4 to flow-sensor adapter | 1 | probable | `adapter pneumatic flow pressure sensor v2.stl` |
| Flow/pressure sensor to G1/4 | 1 | probable | `connector tube to flow sensor 1_8 v1.stl` |
| Throttle valve frame | 1 | yes | `frame_updated.stl` (supersedes `frame_flowvalve.stl`) |
| Throttle valve adapter | 1 | yes | `adapter_flowvalve.stl` |
| **Tube holder** | 4 | **NO** | — |
| **Sensor holder** | 1 | **NO** | — |
| **IR-sensor holder** | 1 | **NO** | — |
| **IR-sensor interruptor disc** | 1 | **NO** | — |
| **Load-cell attachment** | 2 | **NO** | — |
| Torquemeter base plate | 1 | yes | `Torquemotor base complete.stl` |
| Torquemeter clutch | 2 | yes | `friction part 11mm.stl`, `friction thingy 11.2mm.stl` |
| Torque meter holder | 1 | yes | `holder friction torquemotor.stl` |
| Brake rotor | 1 | yes | `Rotor Torquemotor 35mm.stl` or the 32 mm variant |
| Output shaft stabiliser | 1 | yes | `coupling output shaft stabilizer.stl` |
| Engine mounting base | 1 | yes | `Engine mounting base.stl` |

**Five printed part types have no CAD in any archive.** All five carry an
instrument. They are the tube holder, sensor holder, IR-sensor holder, IR
interruptor disc and load-cell attachment. See `MISSING_FILES.md`.

---

## 1.9 Approximate cost of one bench

Taking one of each item at the unit prices above and amortising the pack purchases,
a single bench is roughly **€300–350** in bought parts, plus about €11 of filament.
The dominant costs are the Dynamixel chain (U2D2 + U2S2 + SMPS + AX-12A ≈ €163) and
the sensors (≈ €60). The 2023 SpringRC generation was far cheaper but is the reason
the servo was replaced.

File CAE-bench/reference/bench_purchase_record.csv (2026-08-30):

category | part | supplier | description_on_invoice | qty_or_pack | cost_eur | notes
tank | Fire extinguisher 2 kg | Amazon.nl | Smartwares 10.014.68 Brandblusser poeder 2 kg ABC rood | 1 | 27.29 | Tank used as the pneumatic battery for the experimental setup
tank | Fire extinguisher 1 kg | Amazon.nl | Smartwares 10.018.56 (BB1) Brandblusser Poeder 1 kg ABC | 1 | 29.00 | Tank for the experimental setup and the rover
tank | Fire extinguisher foam 2 L | Amazon.nl | Smartwares SW SB2 SB2 Brandblusser Schuim 2 liter AB | 3 | 71.97 | First set converted to ballast configuration
tank | Fire extinguisher foam 2 L | Amazon.nl | Smartwares SW SB2 SB2 Brandblusser Schuim 2 liter AB | 2 | 47.98 | Second set converted to ballast configuration
tank | Fire extinguisher 1 kg ABC | IFSS B.V. via bol.com | ANAF Group Brandblusser 1 kg Poederblusser ABC | 5 | 114.75 | Final artifact tanks
tank | Fire extinguisher 1 kg ABC | IFSS B.V. via bol.com | ANAF Group Brandblusser 1 kg Poederblusser ABC | 6 | 137.70 | Pressure vessels for design cycle 2 rovers
pneumatic | Elbow fitting 8mm x 1/8 BSP | Amazon.nl | TAILONZ PNEUMATIC Mannelijke Elleboog 8mm Buis OD x 1/8 BSP Push | pack | 13.49 | 90 degree fittings
pneumatic | Straight fitting PC8-01 | Amazon.nl | TAILONZ PNEUMATIC Mannelijke Rechte 8mm Buis OD x 1/8 BSP Push | 10 | 9.99 | First set
pneumatic | Straight fitting PC8-01 | Amazon.nl | TAILONZ PNEUMATIC Male Straight 8mm Tube OD x 1/8 BSP PC8-01 | 10 | 9.99 | Second set
pneumatic | Straight fitting PC8-01 | Amazon.nl | TAILONZ PNEUMATIC Mannelijke Rechte 8mm Buis OD x 1/8 BSP | 10 | 9.99 | Third set
pneumatic | Straight fitting | Amazon.nl | Bwintech 12 Pcs 8mm Buis OD x 1/8 Mannelijke BSP Draad Rechte Push | 12 | 11.49 | Better delivery time than the first ones
pneumatic | Straight fitting | Amazon.nl | Bwintech 12 Pcs 8mm Buis OD x 1/8 Mannelijke BSP Draad Rechte Push in | 12 | 20.48 | Design cycle 2
pneumatic | Quick connector adapter | Amazon.nl | 10 stks Pneumatische Quick Connector Air Fittings Adapter 8mm 1/4BSP | 10 | 12.72 | Fourth set of fittings
pneumatic | Quick connector adapter | Amazon.nl | 10 stks Pneumatische Quick Connector Air Fittings Adapter 8mm | 10 | 6.44
pneumatic | T-piece | CNCTEC UG via Amazon | Pneumatische meervoudige steekschroefverbinding TE 1/4 - 8mm IQS T-stuk perslucht | set | 38.72 | Second set of pneumatic valves/fittings
pneumatic | Ball valve BVU-8 | Amazon.nl | TAILONZ PNEUMATIC 8mm OD Kogelklep Luchtstroom Regelklep Push | 1 | 18.99
pneumatic | Ball valve BVU-8 | Amazon.nl | TAILONZ PNEUMATIC 8mm OD Kogelklep Luchtstroom Regelklep Push | 2 | 37.98
pneumatic | Ball valve BVU-8 | Amazon.nl | TAILONZ PNEUMATIC 8mm OD Ball Valve Air Flow Control Valve BVU-8 | 5 | 75.96 | First set of pneumatic valves
pneumatic | Ball valve | Amazon.nl | ERGAOBOY 5 Pcs 8mm OD Pneumatische Kogelkraan | 5 | 18.99 | Used on the rovers
pneumatic | PU hose 8mm OD 5mm ID | Amazon.nl | HUAZIZ 8mm OD 5mm ID Pneumatic Air Hose PU Hose 12m Blue | 12 m | 29.98
pneumatic | PU hose 8mm OD | Amazon.nl | TAILONZ PNEUMATIC Blauw 8mm OD 10 Meter PU de Pijpslang | 10 m | 15.99
pneumatic | Splitters | Amazon.nl | TAILONZ PNEUMATIC 8mm OD Push to Connect Fittings Pneumatische | pack | 17.99 | Distributing air between cylinders
pneumatic | O-ring set | Bol.com | O-ringset 32 maten 419 delig NBR Rubber | 419 | 17.45 | Sealing the pneumatic system
pneumatic | Compressor accessories | Lemato | HBM 5 Delig Luchtgereedschapset | 1 | 26.90 | Hose and accessories for the HBM compressor
sensor | Flow sensor | Amazon.nl | SENSTREE G1/2 Mannelijke Draad Messing Water Flow Sensor | 1 | 16.11 | Water turbine sensor used on air
sensor | Flow sensor | Amazon.nl | SENSTREE G1/2 Mannelijke Draad Messing Water Flow Sensor | 1 | 16.11 | Second unit
sensor | Pressure sensor G1/4 | Amazon.nl | Druksensor G1/4 Drukomvormer Sensor Ingang 5V Uitgang 0.5-4.5V | pack | 57.21 | 0-100 psi
sensor | Photo interrupter | Vanallesenmeer.nl | GP1A57HRJ00F Photo Interrupter | 1 | 16.85 | Measures engine output velocity
sensor | Photo interrupter breakout | Vanallesenmeer.nl | Photo Interrupter Breakout Board | 1 | 5.85 | SparkFun
sensor | Photo interrupter | Vanallesenmeer.nl | GP1A57HRJ00F Photo Interrupter | pack | 49.50 | Additional units
sensor | Photo interrupter set | Vanallesenmeer.nl | GP1A57HRJ00F Photo Interrupter and Breakout Board SparkFun | pack | 51.30 | Closing the control loop
sensor | Load cell 500 g | Amazon.nl | Gewicht Sensor Silver 500g and hx711 B0CJ93Y21V | 1 | 18.33 | Measuring engine torque indirectly
sensor | Load cell 1 kg | Amazon.nl | HALJIA Draagbare elektronische gewichtssensor laadcel weegsensor 1KG | 1 | 7.99 | First item
sensor | Load cell 1 kg | Amazon.nl | HALJIA Draagbare elektronische gewichtssensor laadcel weegsensor 1KG | 1 | 7.99 | Second item
sensor | Load cell 1 kg | Amazon.nl | HALJIA Draagbare elektronische gewichtssensor laadcel weegsensor | pack | 15.98
sensor | Load cell 100 g | Amazon.nl | 0-100g zeer nauwkeurige digitale parallelle straal elektronische | 1 | 10.60 | Measuring engine torque indirectly
sensor | HX711 amplifier | Amazon.nl | ICQUANZX HX711 ADC converter breakout module digitale weegcel 1KG | 1 | 6.99 | Load cell amplifier
mechanical | Bearing 6802 2RS | Lagerkoning.nl | IBB Kogellager 6802/61802 2RS 15x24x5mm | pack | 32.28 | Bearing B in the Wankel
mechanical | Bearing R188 | Lagerkoning.nl | IBB Miniatuur Kogellager R188 6.35x12.7x3.18mm | pack | 32.28 | SUPERSEDED - see R188 ZZ
mechanical | Bearing R188 ZZ | Lagerkoning.nl | IBB Miniatuur Kogellager R188 ZZ 6.35x12.7x4.76mm | pack | 82.45 | Bearing A - THIS IS THE ONE IN USE
mechanical | Bearing R188 ZZ | Lagerkoning.nl | IBB Miniatuur Kogellager R188 ZZ | 4 | 11.95 | Design cycle 2
mechanical | Bearing 6802-2RS | Amazon.nl | 10 stuks groefkogellagers 6802-2RS 15x24x5mm | 10 | 13.30
mechanical | Bearing 6802-2RS | Amazon.nl | 6802-2RS bearings | 10 | 8.50 | Wankel engines design cycle 2
mechanical | Flexible shaft coupling | Okaphone | OKFLEX Flexibele as Koppeling | 1 | 24.15 | Improved engine mounting
mechanical | Corner bracket | Amazon.nl | Alberts 330330 Hoekanker extra sterk met rib sendzimir verzinkt | pack | 54.48
mechanical | M5 lock nuts | Amazon.nl | Jeboler M5 moeren 100 stuks zelfborgende A2 V2A 304 DIN 985 | 100 | 12.52
mechanical | M3 square nuts | Amazon.nl | 100 stuks M3 DIN557 metrische draad vierkante moeren SS304 | 100 | 6.10 | Wankel top cover
mechanical | Graphite | Amazon.nl | STAEDTLER Mars Micro Carbon 250 1.3mm HB Potlood Vullingen | pack | 7.67 | Apex seals and lubrication
mechanical | Graphite sticks | sostrene grenes | Graphite sticks | pack | 1.24 | Sealant for the Wankel
mechanical | Super glue | Amazon.nl | Orzanne 18 x secondelijm extra sterk alleslijm snellijm 100 g | 18 | 11.99
mechanical | Wood and screws | Hornbach | Wood screws and other materials | - | 72.25 | Wood planks o-rings and other items for the setup
electrical | Arduino Uno | - | Arduino UNO | 1 | 26.50 | From the TA bench BOM
electrical | Breadboard | AZDelivery | AZDelivery Mini Breadboard 400 Pin met 4 Busbars | pack | 15.96 | Rapid prototyping of the sensor wiring
electrical | Crimping tool | Amazon.nl | Homca SN-28B Krimptang 0.14-1 mm2 met 2030 Dupont-krimpconnectoren | 1 | 38.99 | Custom cables and connectors
electrical | Jumper wires and tape | Okaphone | PVC isolatietape Set Draadbruggen Male/Female Set soepele draadbruggen | set | 16.20 | Completing the setup wiring
electrical | 9V clip to DC jack | Kiwi Electronics | 9V Batterij clip naar 2.1mm DC plug | 1 | 10.75 | Standalone power
electrical | Cable adapter | Michele Chiapello | kabeladapter 9 V CLIP DC 2.1 JACK | 1 | 7.48
tooling | Magnetic bit holder | Daw21onlineshop | Magnetische bithouder 60mm lang 1/4 bit houder | 1 | 6.65 | Workshop tool
tooling | 3D printer nozzles | Amazon.nl | 24 pcs 0.2/0.3/0.4/0.5/0.6/0.8/1.0mm Messing MK8 3D Printer Nozzles | 24 | 10.99 | Used to regulate air flow in the turbine engine
tooling | Ultimaker limit switches | Makerpoint | Ultimaker Limit Switches | pack | 50.61 | Repair kit for the Ultimaker printers
misc | Magnets | Supermagnete.nl | Supermagneten used as payloads for the compressed-air engines | pack | 33.20 | Part of the load for the experimental setup
misc | Hardware bundle | Amazon.nl | Several hardware for the compressed air engines | - | 466.98 | Combined invoice

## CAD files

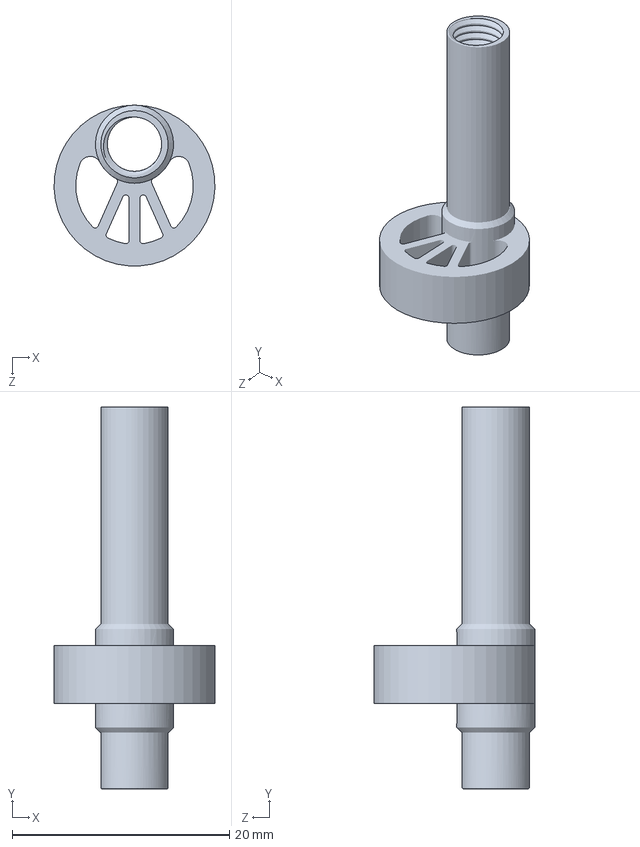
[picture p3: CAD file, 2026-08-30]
CAE-bench/cad/wankel-2023/Random/crank rotary_full_thread1.SLDPRT
14.8 x 35.2 x 14.8 mm

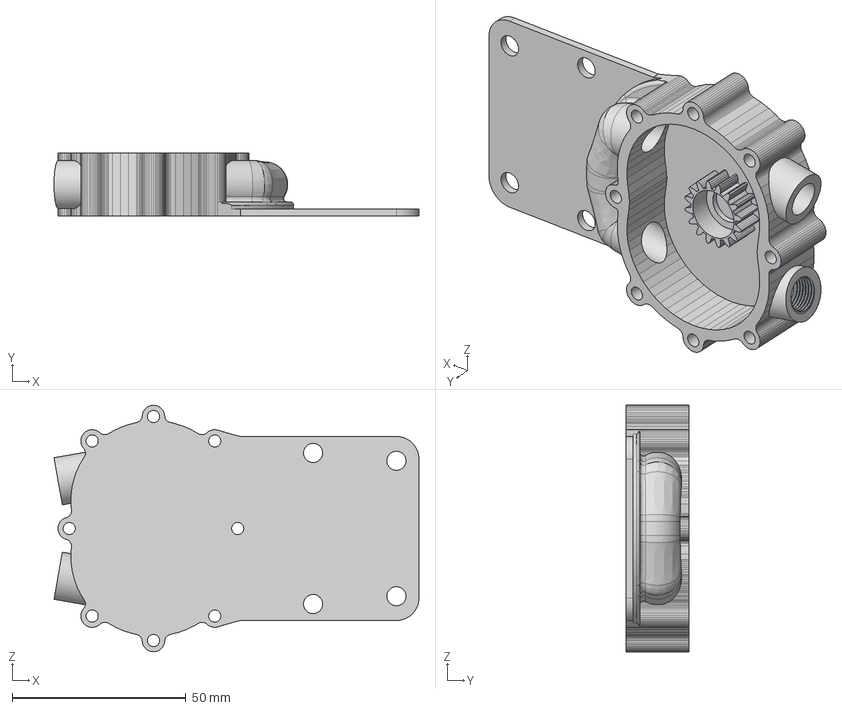
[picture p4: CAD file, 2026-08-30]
CAE-bench/cad/wankel-2023/Random/mainframe_wankel.step
105.1 x 18.0 x 71.0 mm

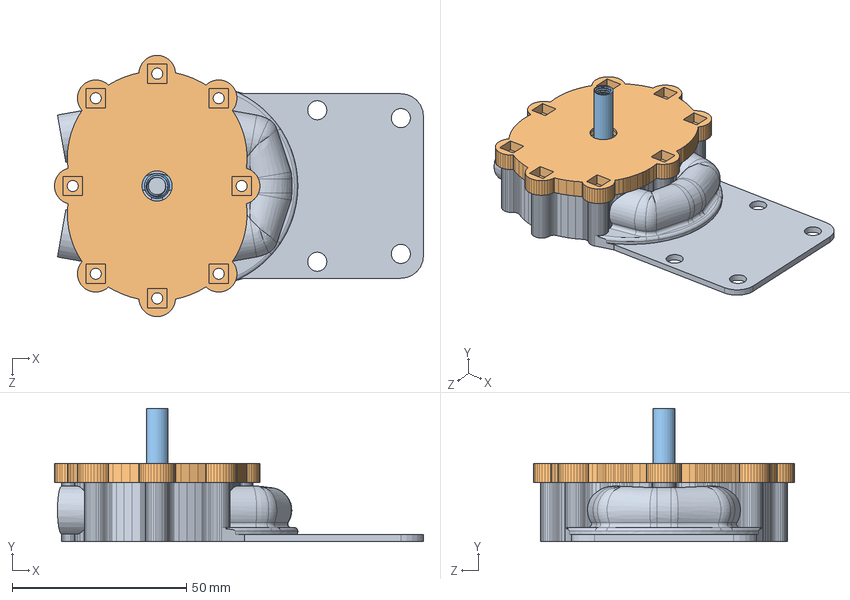
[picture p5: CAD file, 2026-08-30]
CAE-bench/cad/wankel-2023/Wankel assembly.SLDASM
105.9 x 38.2 x 75.0 mm
mainframe_wankel.step
Topcover_wankel.step
crank rotary
rotor.step

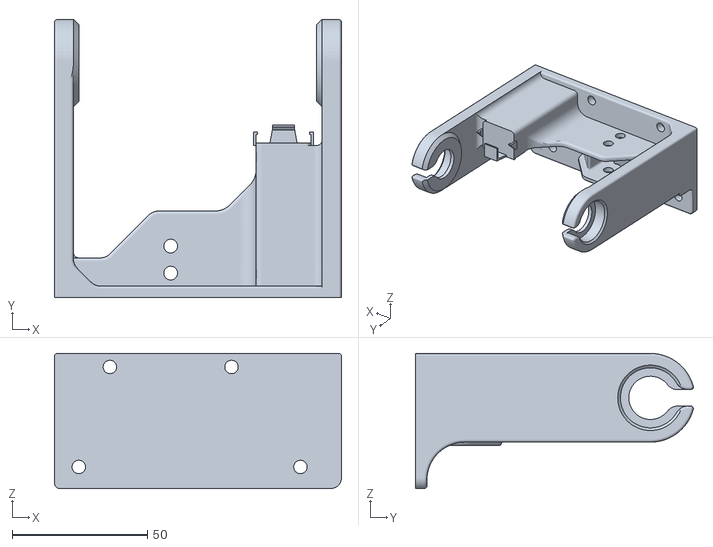
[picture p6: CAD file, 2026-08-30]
CAE-bench/cad/torquemeter/Torquemotor base complete.stl
106.2 x 102.8 x 50.0

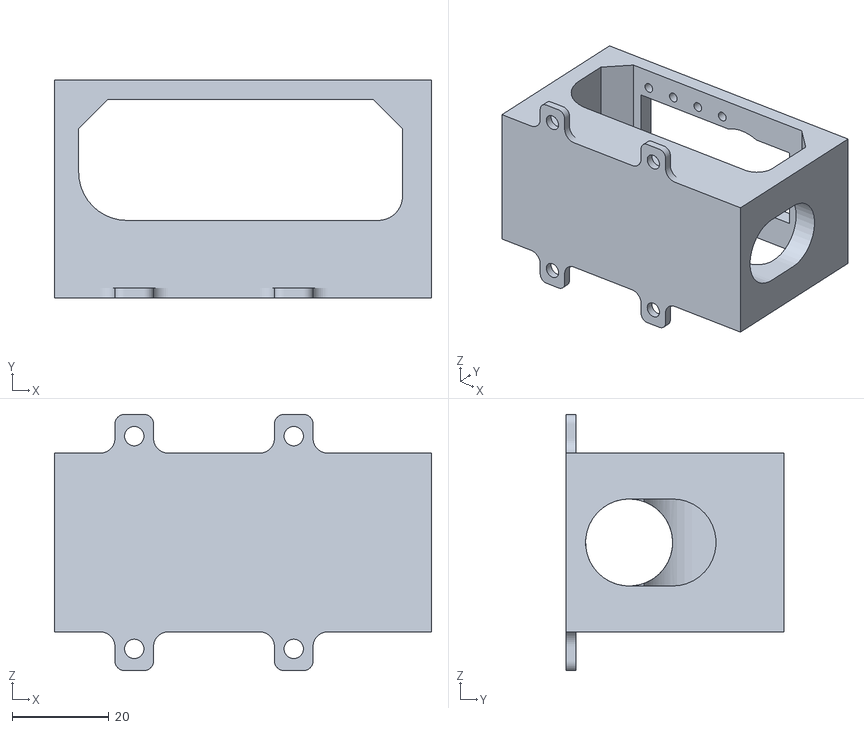
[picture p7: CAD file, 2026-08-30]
CAE-bench/cad/aart-2024/CAEfinal.STL
78.0 x 45.0 x 53.0

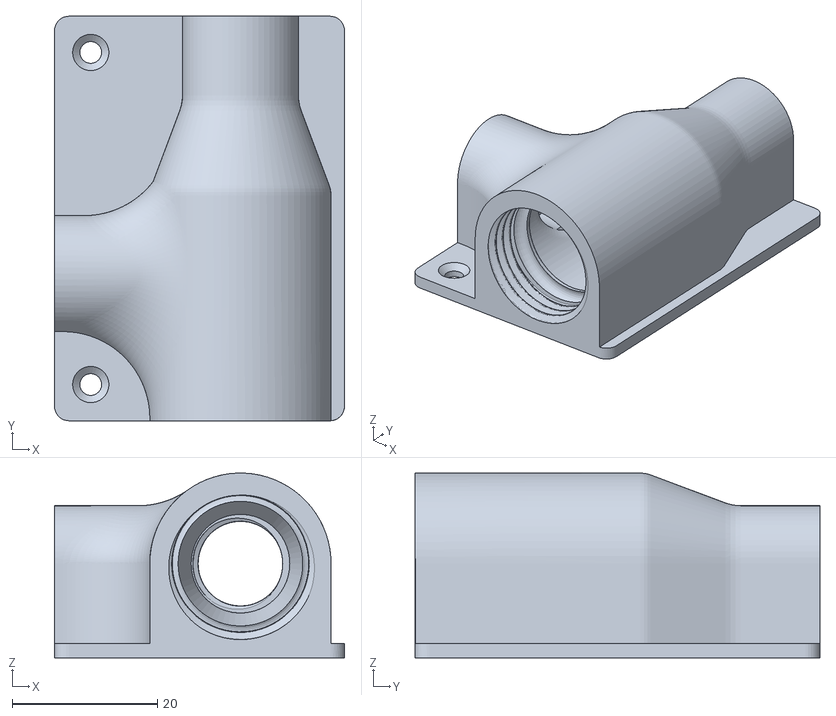
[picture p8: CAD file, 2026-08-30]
CAE-bench/cad/pneumatics/adapter pneumatic flow pressure sensor v2.stl
40.0 x 55.8 x 25.5

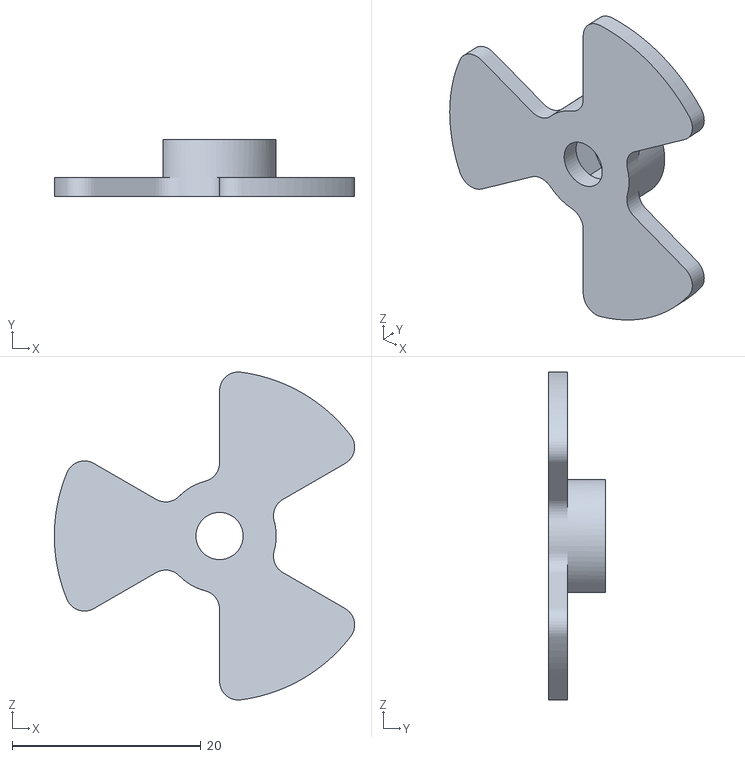
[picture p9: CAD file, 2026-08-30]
CAE-bench/cad/torquemeter/Rotor Torquemotor 35mm.stl
31.8 x 6.00 x 34.7

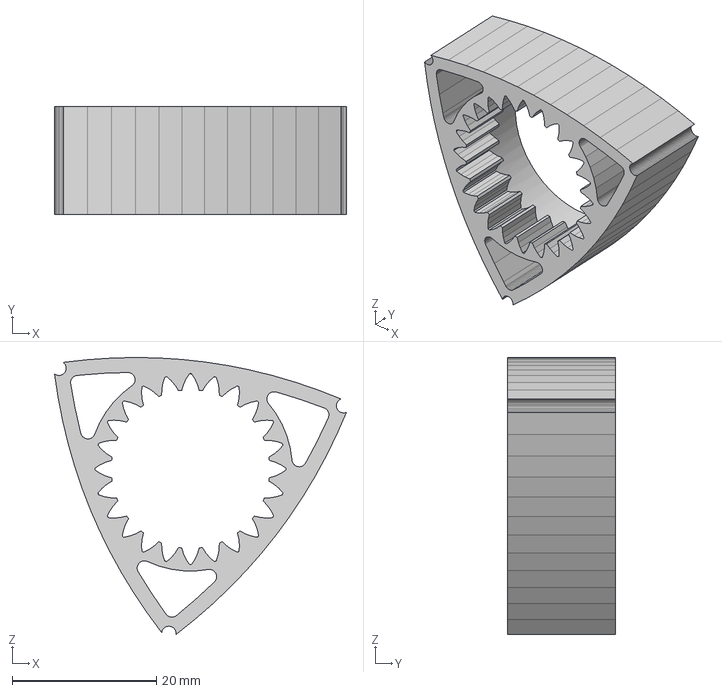
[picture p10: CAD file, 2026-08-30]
CAE-bench/cad/wankel-2023/Random/rotor.step
40.5 x 15.0 x 38.4 mm

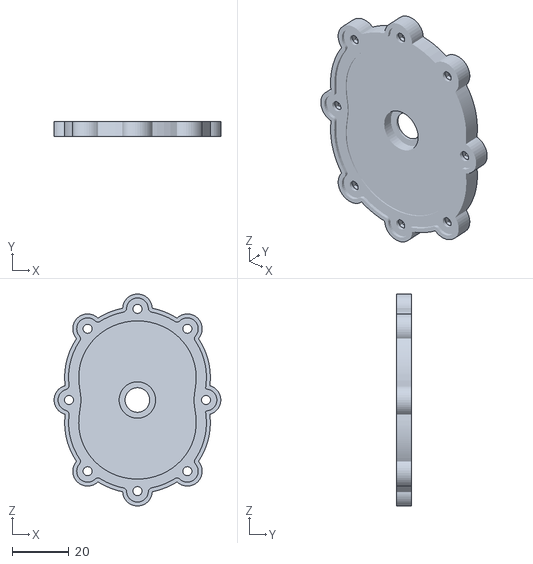
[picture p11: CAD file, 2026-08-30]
CAE-bench/cad/wankel-2023/Wankel topcover.stl
59.0 x 5.40 x 75.0

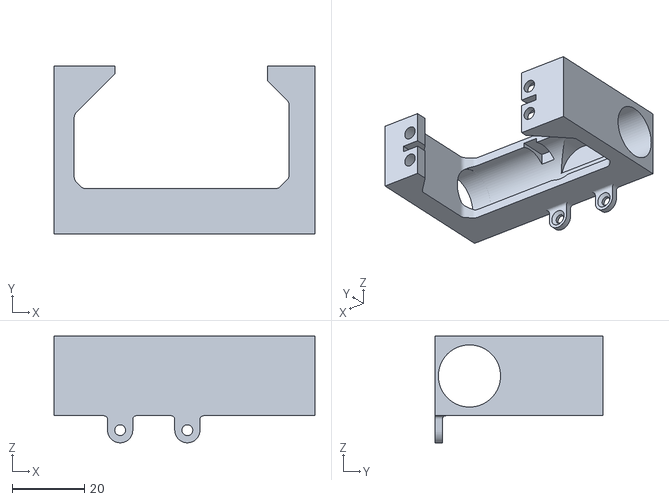
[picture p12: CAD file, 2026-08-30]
CAE-bench/cad/pneumatics/frame_flowvalve.stl
72.2 x 46.4 x 29.5

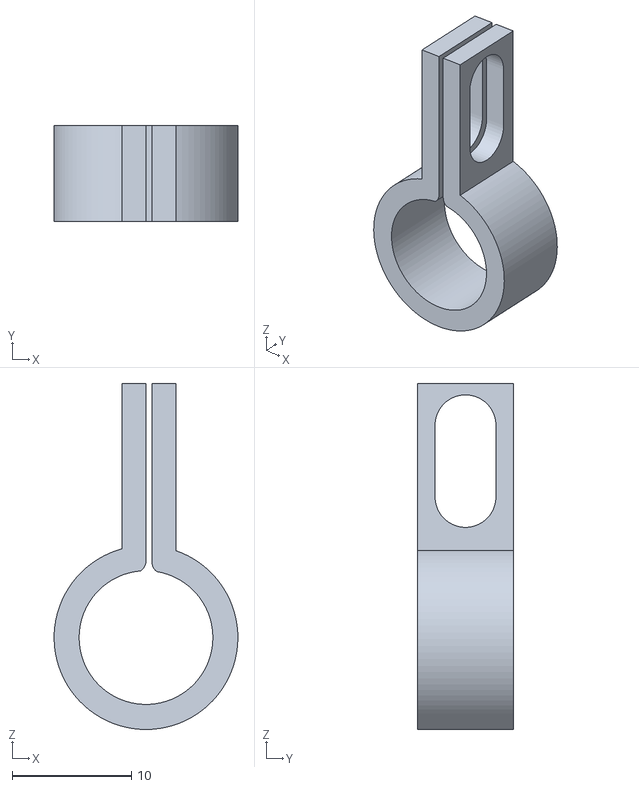
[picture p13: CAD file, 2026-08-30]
CAE-bench/cad/torquemeter/holder friction torquemotor.stl
15.4 x 8.00 x 29.0

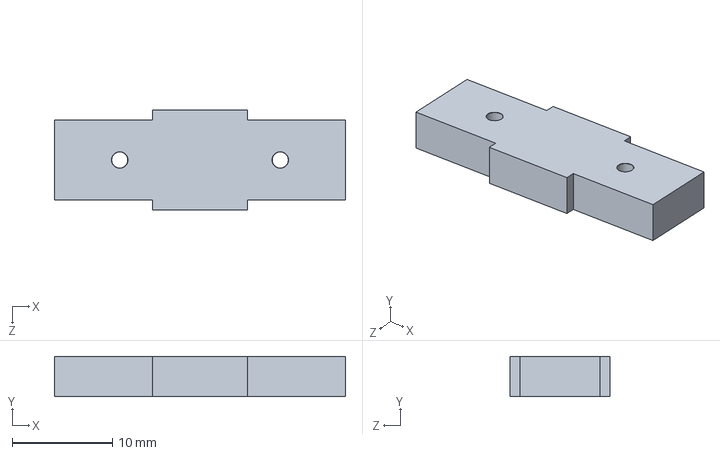
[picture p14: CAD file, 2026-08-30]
CAE-bench/cad/aart-2024/CAEconnect.SLDPRT
29.0 x 4.00 x 10.0 mm

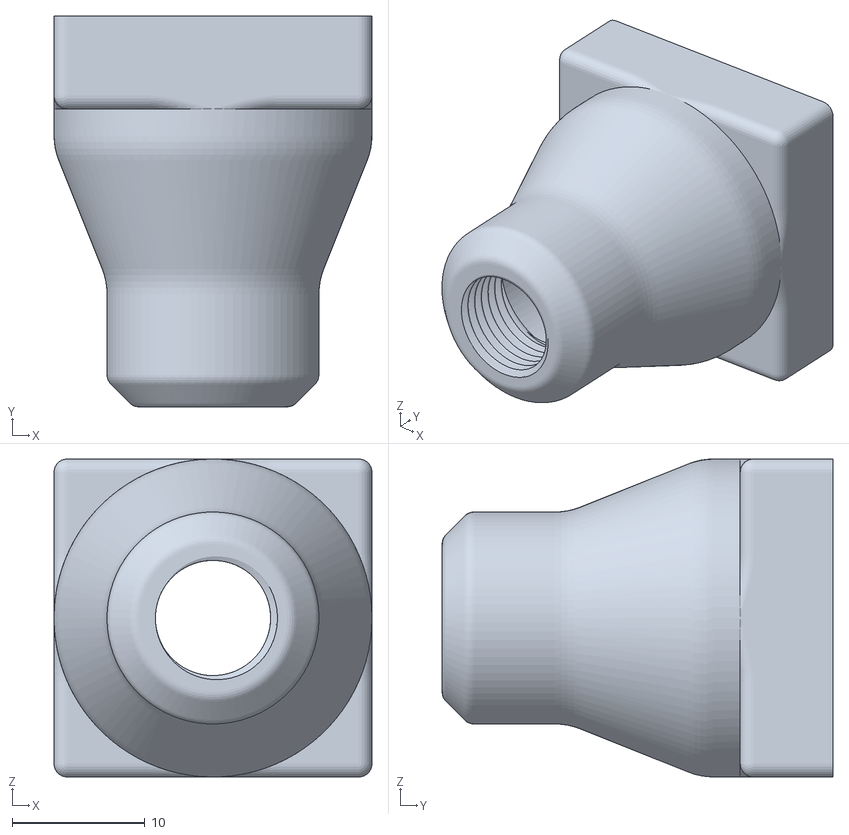
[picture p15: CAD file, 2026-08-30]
CAE-bench/cad/pneumatics/connector tube to flow sensor 1_8 v1.stl
24.0 x 29.5 x 24.0

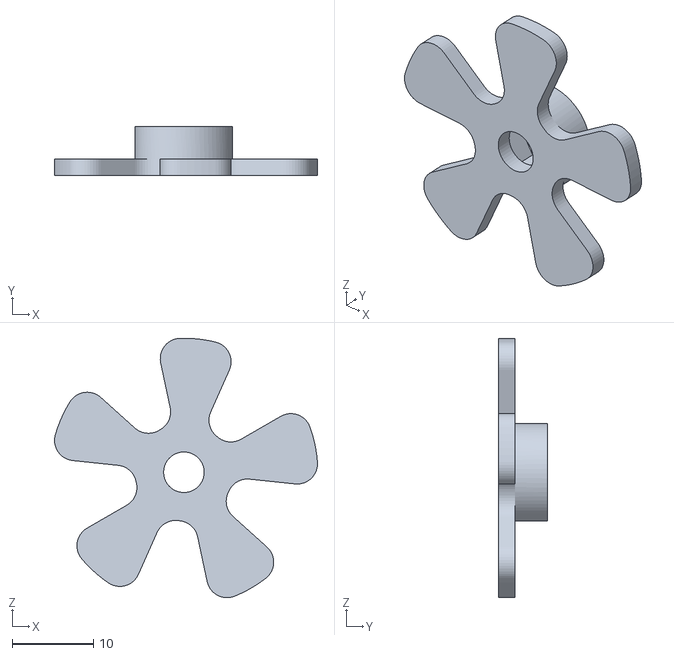
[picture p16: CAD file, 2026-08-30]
CAE-bench/cad/torquemeter/rotor torquemotor speed (v1~recovered).stl
32.4 x 6.00 x 31.9

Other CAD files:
CAE-bench/cad/wankel-2023/Wankel mainframe.stl
CAE-bench/cad/wankel-2023/Random/crank rotary_full_thread.STEP
CAE-bench/cad/aart-2024/UMS5_CAE8.3mf
CAE-bench/cad/wankel-2023/crank rotary.SLDPRT
CAE-bench/cad/aart-2024/CAE(1).SLDPRT
CAE-bench/cad/pneumatics/adapter_flowvalve.stl
CAE-bench/cad/pneumatics/frame_updated.stl
CAE-bench/cad/torquemeter/Engine mounting base.stl
CAE-bench/cad/torquemeter/MCDC project print.3mf
CAE-bench/cad/torquemeter/coupling output shaft stabilizer.stl
CAE-bench/cad/torquemeter/friction part 11mm.stl
CAE-bench/cad/torquemeter/friction thingy 11.2mm.stl
CAE-bench/cad/torquemeter/rotor torquemotor 32mm.stl
CAE-bench/cad/torquemeter/torquemotor base only base.stl
CAE-bench/cad/wankel-2023/GT2_80T_8mm_Bore_Pulley_for_10mm_Belt.step.SLDPRT
CAE-bench/cad/wankel-2023/Pulley 15T 3mm.stp.SLDPRT
CAE-bench/cad/wankel-2023/Random/Casing1-8.SLDPRT
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

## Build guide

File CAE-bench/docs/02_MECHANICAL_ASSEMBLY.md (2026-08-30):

# 2 — Mechanical assembly

Build order: **engine first, then bench, then actuator, then sensors.** The engine
must spin freely by hand before anything else is attached to it.

Safety first — read §0 before charging the tank.

---

## 0. Safety

Verbatim from the 2024 assembly manual (Damien Dufour, 6 February 2024):

> Since you'll be dealing with pressurized air, wearing **safety glasses at all times
> is a must**, especially when the external storage tank is being filled or is full.
> […] Given that some engines can reach extremely high RPMs, prioritizing safety
> cannot be overstated. […] Before you run your engine, thoroughly inspect it for air
> leaks.

Three additions from what the archive shows actually happened:

1. **8 bar is the ceiling.** The tank is a converted fire extinguisher.
2. **The engine reaches ~2700 rpm unloaded at the normal operating point**, and over
   7000 rpm in the 10 bar test. Printed parts leaving a rotor at that speed are
   dangerous. Do not stand in the plane of the rotor.
3. Aart's own future-work section: *"running the experiment at full force can not be
   considered safe, the screws in the current connecting piece loosen due to the high
   vibrations and rotational force and get launched at high speed."* **Fit a guard,
   and thread-lock the coupling screws.**

---

## 1. Wankel engine sub-assembly

Print list: mainframe, top cover, rotor, crank. Tough PLA, 0.2 mm layers.

**Step 1 — Graphite the chamber.** Apply graphite to the inside of the
epitrochoid-shaped chamber. Coat it well; the graphite is both the lubricant and the
air seal. Flip the chamber upside down and tap out the excess.

**Step 2 — Bearing into the rotor.** Press one **Bearing B** (6802, 15 × 24 × 5 mm)
into the rotor with your thumbs until it seats.

**Step 3 — Apex seals.** Apply super glue to the inserts at the three corners of the
rotor, then push a **15 mm length of graphite** into each. Sand each corner down
until it is flush with the adjacent face.

**Step 4 — Crank into the rotor.** Insert the crank into the centre of the bearing,
**smaller rod facing down**. It must be a tight fit. *Lateral play in the crank costs
a large amount of efficiency* — this is the single most common build fault.

**Step 5 — Crank bearings.** Place one **Bearing A** (R188 ZZ, 6.35 × 12.7 × 4.76 mm)
on the top of the crank shaft, pushed flush with the extruding edge of the rod. Repeat
on the bottom.

**Step 6 — Rotor into the chamber.** Drop the rotor assembly into the main chamber
with the **gear teeth aligned**. The lower crank bearing sits in the centre pocket of
the main chamber. Twist the top rod by hand: the rotor must sweep the chamber with no
jamming. **If it jams, take it apart and start again** — do not force it.

**Step 7 — Top cover.** Place the top cover on the chamber with all holes aligned to
the cut-out inserts.

**Step 8 — Close it up.** Insert **6 × M3 square nuts** into the inserts of the top
chamber, then screw **6 × M3 screws** in from the underside. Tighten evenly.

Check: the assembled engine should spin for a second or two from a flick of the shaft.

---

## 2. Bench frame

The bench is a 30 × 40 cm wooden plank with everything screwed down to it.

1. Mount the **tank holder** (supplied with the extinguisher) at one end. Screw
   through with 3 × 12 T10 wood screws.
2. Mount the **Arduino holder** near the opposite corner, away from the air line.
3. Mount the **corner bracket** — this carries the engine and, later, the brake.
4. Mount the **engine mounting base** (`Engine mounting base.stl`) to the bracket.
5. Fit the engine to the base. Support the output shaft with the two **5 mm bearings**
   and the **OKFLEX flexible coupling** so that shaft misalignment does not load the
   printed crank.

The flexible coupling matters. It was bought in January 2024 specifically as an
"enhanced mounting strategy" after the rigid mounting caused problems.

---

## 3. Actuator: valve + servo bracket

This is the part `cad/aart-2024/` covers in full. See `docs/CAD.md` for measured
dimensions and `cad/aart-2024/CAEfinal_views.png` for the drawing.

1. **Print `CAEfinal.STL`.** Tough PLA red, **100 % infill, 15 mm/s**, 5 walls,
   0.2 mm layers, **tree support in PVA**, no build-plate adhesion. About 17 h 42 on
   an UltiMaker S5. The 100 % infill is not optional — this part takes the servo
   reaction torque.
2. **Print `CAEconnect.SLDPRT`** (the horn). It screws into the AX-12A horn at the
   top and bottom holes, **16 mm apart**.
3. **Snap the ball valve into the bracket.** The Ø17.87 mm bore in the left wall is a
   tight fit by design: it constrains the valve in every direction but vertical, and
   pressing it up against the servo removes that last degree of freedom.
4. **Mount the AX-12A** along the top of the bracket, secured on both sides.
5. **Bolt the bracket to the plank** through the four Ø3.96 mm feet — **M4**, on the
   33.00 × 44.00 mm pattern.
6. Fit the horn between the servo output and the valve stem. Tolerance here is
   critical; a loose horn shows up as vibration and lost accuracy.

**Design intent, in Aart's words:** the valve is mounted at the same height as the
tubing so the 8 mm line bends as little as possible, raising the tube height by only
1 mm. The side windows exist so the user can see the control input applied to the
valve.

---

## 4. Torque rig (optional, and never used — see the note)

The parts exist and print. Nothing in any report used them.

1. Print `Engine mounting base.stl`, `Torquemotor base complete.stl`,
   `holder friction torquemotor.stl`, one brake rotor (32 mm or 35 mm), one friction
   element (11 mm or 11.2 mm), and `coupling output shaft stabilizer.stl`.
2. The coupling takes the engine output shaft to the brake rotor.
3. The friction element bears on the rotor; the reaction is read by a load cell on a
   known arm.
4. Wire the load cell to an **HX711** and read it on a spare Arduino input.

**Status:** the load cells were bought and fitted to the 2024 bench (they are in
Aart's BOM as `Load cell 500g/1kg`, qty 2). The **load-cell attachment bracket has no
CAD**, and no firmware ever read the channel. Closing this is the single highest-value
improvement to the bench. See `docs/06_KNOWN_ISSUES.md` §T.

---

## 5. Final checks before first run

- [ ] Engine spins freely by hand, no jamming
- [ ] All 6 M3 cover screws tight, square nuts seated
- [ ] Servo bracket bolted down with M4, horn engaged, no play
- [ ] Hand shut-off valve fitted and **closed**
- [ ] All push-fit joints fully inserted (push until the collet clicks, then tug)
- [ ] Soap-water leak test at 2 bar before going to 8
- [ ] Eye protection on
- [ ] Guard between you and the rotor plane

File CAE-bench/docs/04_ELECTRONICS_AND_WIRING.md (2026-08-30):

# 4 — Electronics and wiring

## 4.1 Architecture, 2024 generation

```
   PC or Raspberry Pi 5                         12 V SMPS
      |                                             |
      | USB serial 19200 baud, JSON lines           |
      |                                          [ U2S2 power hub ]
   [ Arduino Uno Rev 3 ]                            |  3-pin TTL
      |  5 V rail                                   |
      |                                          [ AX-12A servo ] -- horn -- ball valve
      +-- A0  <-- pressure sensor  (analog 0.5-4.5 V)
      +-- D2  <-- flow sensor      (digital pulse, INT, RISING)
      +-- D3  <-- IR interrupter   (digital pulse, INT, FALLING)
      |
      +-- USB (separate port) --> PC --------- U2D2 USB-to-TTL --> U2S2
```

The Arduino is used **only as an ADC and pulse counter**. All control runs on the PC.

## 4.2 Pin map — this is fixed by the firmware

| Signal | Pin | Mode | Why this pin |
|---|---|---|---|
| Pressure sensor | **A0** | analog in | the only analog channel used |
| Flow sensor | **D2** | `INPUT_PULLUP`, `attachInterrupt`, RISING | the Uno supports external interrupts only on D2 and D3 |
| IR photo interrupter | **D3** | `INPUT`, `attachInterrupt`, FALLING | as above |
| Serial | USB | 19200 baud | must match `CAEPC.py` |

Power and ground for all three sensors come from the Arduino 5 V and GND rails.

## 4.3 Why 5 V, and why the Arduino stayed

Aart's design decision, worth preserving: the flow, pressure and IR sensors all
require 5 V and return 5 V logic or analog. A 3.3 V controller would need a separate
5 V supply plus level shifters. The Raspberry Pi 5 has 3.3 V GPIO and **no ADC at
all**, which is why the Arduino remains in the chain purely to digitise A0 and to
count the two interrupt lines.

His conclusion after building it: *"The Raspberry Pi 5 proved to be unnecessary, since
the same functionality is achieved by running the code on a laptop or PC with less
effort."* **Build it with a laptop.** The Pi adds cost and no capability.

## 4.4 Dynamixel chain

| Setting | Value |
|---|---|
| Protocol | 1.0 |
| ID | 0 |
| Baud rate | 1 000 000 |
| Port (Windows) | `COM8` in the shipped code |
| Torque enable address | 24 |
| Goal position address | 30 |
| Present position address | 36 |
| Position range used | **200 to 512** |
| Angular span | 90 degrees, so 0.288 deg per unit |
| Moving status threshold | 0.5 units |

Use **Dynamixel Wizard** to confirm the ID, baud and COM port before running anything.

> **Convention warning.** In `CAEPC.py` position **200 is declared fully closed** and
> **512 fully open**. Max Kloosterman's rover mounts the same servo the other way
> round: 204 is 0 degrees and that is where the aperture is *maximum*. Both are
> internally consistent; they are different physical mountings. Verify yours by
> watching the valve before you trust either sign.

## 4.5 Load cell, if you fit one

Not present in any working firmware. To add it:

- Load cell (500 g or 1 kg) -> **HX711** breakout -> two digital pins (DT, SCK)
- The HX711 library `HX711_ADC` was already used on an adjacent project in 2022
- Add a `force` field to the JSON the Arduino publishes and a column to the Excel
  writer in `CAEPC.py`. That is the whole change.

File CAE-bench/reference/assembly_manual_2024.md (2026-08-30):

# Compressed-air engines assembly manual

**Damien Dufour, Mechanical Craftsmanship, 6 February 2024**

Transcribed from `Compressed_air_engine_assembly_manual (4).pdf`. **The technical
drawings are not reproduced** — download the original for those. This manual covers
three engines; the bench in this repository uses the Wankel.

---

## 1. Safety precautions for engine testing and assembly

Before you dive into assembling and testing your engines, it's crucial to understand
and follow certain safety guidelines and procedures.

First off, since you'll be dealing with pressurized air, wearing safety glasses at all
times is a must, especially when the external storage tank is being filled or is full.
This simple precaution ensures that your eyes are protected in case any component
unexpectedly detaches or breaks.

When you're ready to fill and test your engine, it's important to get clearance from a
teaching assistant (TA). Your engine must pass a safety inspection by the TA, who will
check that it's been correctly assembled and is safe for testing. Given that some
engines can reach extremely high RPMs, prioritizing safety cannot be overstated.

Understanding the pressure limits of your engine is critical. Exceeding these limits
can cause severe damage, including parts breaking away or the engine failing
altogether. Before you run your engine, thoroughly inspect it for air leaks. Fixing
these leaks before proceeding is essential to maintain efficiency and prevent damage.
Also, the use of appropriate tools for assembly and adjustments is crucial to ensure
the engine's integrity and your safety.

Finally, make sure to maintain a clean and organized workspace.

---

## 2. Wankel rotary engine

A compressed air-powered, 3D-printed Wankel rotary engine works by combining creative
design with effective energy conversion. Its triangular rotor, which is specially made
to spin inside an epitrochoid-shaped chamber, is essential to how it works. The
pressurized air that is kept in external tanks is drawn in by the engine to start its
cycle. The compressed air expands as it enters the chamber and presses up against the
sides of the rotor, starting it in motion. After being transmitted to a central output
shaft, this rotation provides mechanical power. The expanded air is discharged after
energy transfer, concluding the exhaust phase. The engine is suitable at both low and
high pressures.

### 2.1 Bill of materials

| Part | Description | Qty |
|---|---|---|
| Base cover | Base of the engine, has the extruding pipes and attachment to the clutch system | 1 |
| Rotor | | 1 |
| Crank | | 1 |
| Bearing A | Small bearings | 2 |
| Bearing B | Larger bearing | 1 |
| Top Cover | | 1 |
| Graphite (15 mm) | Comes as a stick, filed down to length | 3 |
| Super Glue | | 1 |
| M3 screw | | 6 |
| M3 square nut | | 6 |

### 2.2 Assembly

**Step 1.** Locate the main epitrochoid-shaped chamber. Apply graphite to the inside
of the chamber. Ensure the chamber is well coated in graphite as it acts as the
lubricant and air sealant. Once thoroughly applied, remove the excess graphite by
flipping the chamber upside down.

**Step 2.** Insert 1 × Bearing B into the rotor by pushing with your thumbs until the
bearing fits snug.

**Step 3.** Apply super glue to the inserts on the 3 corners of the rotor. Following
this, insert a 15 mm piece of graphite into each corner. Using sandpaper, file each
corner down until flush with each adjacent side.

**Step 4.** Insert the crank into the center of the bearing with the smaller rod
facing downwards. Ensure it is a tight and snug fit. This step is crucial as any
lateral movement in the crank can cause the engine to lose a large amount of
efficiency.

**Step 5.** Place 1 × Bearing A on the top of the crank shaft. Push it down the rod
until it is flush with the extruding edge of the rod. Likewise for the bottom, place
1 × Bearing A on the rod and push it down until it is flush with the extruding edge.

**Step 6.** Place the rotary assembly into the main chamber with the gearing teeth
aligned. The bearing on the lower part of the crank should fit in the center pocket of
the main chamber. Once the rotor is in, check for correct rotational movement by
twisting the top rod and ensuring there is no jamming while the rotor spins in the
chamber. If there is jamming, remove the rotor and start again.

**Step 7.** Once the rotor is placed in the chamber without jamming and has a fluid
motion, place the top cover on the chamber, ensuring that all the holes line up with
the cutout inserts.

**Step 8.** Secure the top cover to the main chamber. Insert the 6 M3 nuts into the
inserts of the top chamber. Screw 6 M3 screws from the underside of the engine in
their respective holes. Ensure the top cover is securely attached.

### 2.3 Technical drawings

Not reproduced. The PDF carries dimensioned drawings for the mainframe, the top cover
and the rotor, with the epitrochoid angles called out (20°, 35°, 24.05°, 66.05°).

---

## 3. Single piston engine — summary

Not used on this bench. The PDF gives a full 16-step assembly and an 18-line BOM
including an M1.6 screw, an 8 mm O-ring, a BB bullet used as the inlet valve, brass
tubes, 5 × M2 screws and 120-grit sandpaper. Key technique: sand the cylinder and
piston until no 3D-printing lines are visible and the piston falls out of the chamber
under gravity alone, then graphite both.

## 4. Turbine engine — summary

Not used on this bench. 12-line BOM including 3 × M5 screws, 6 × M5 nuts, 13 spacers,
an M5 threaded drive rod, 2 × Bearing B and rubber sealing tape. Key technique: the
blade openings must face downwards, confirmed by the inserted nut facing the inside of
the chamber — mounted the other way the turbine is highly inefficient and struggles to
spin.

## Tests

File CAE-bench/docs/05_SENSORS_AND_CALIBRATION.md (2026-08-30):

# 5 — Sensors and calibration

Source: `MCDC_Sensor_calibration_procedure.pdf`, **Jelmer Veenhuizen & Quentin
Hopman, 6 November 2023**, reproduced as text in `reference/`. Calibrate in this
order: pressure, flow, force.

---

## 5.1 Pressure sensor

Calibrated against atmosphere. The reading with the sensor open to air corresponds to
1 bar. The datasheet gives 0.5 % output error from non-linearity, hysteresis and
repeatability combined, so zeroing against atmosphere is assumed to hold at 8 bar.

**Procedure**

1. Expose the sensor to atmosphere by decoupling and closing the valves.
2. Wire it: **black to GND, red to 5 V, green to A0**. Connect the Arduino, open the
   Arduino IDE.
3. Run the calibration sketch `calibration_pressure.ino`.
4. Insert the resulting `pressureZero` and `pressureMax` into the experiment firmware.
5. Connect the sensor to the tank charged to 8 bar. Cross-check with the compressor's
   pneumatic pistol pressure dial, in a closed system.
6. Check the value. A discrepancy can come from the dial, a leak, or the calibration
   itself — check all three.

**Values currently in `arduinoADC.ino`:**

```c
const int   pressureZero              = 98;      // ADC counts at 1 atm
const int   pressureMax               = 800;     // ADC counts at full scale
const float pressuretransducermaxPSI  = 100;
const float psiToBarConversion        = 0.0689476;
```

Conversion, verbatim from the firmware:

```
pressureValue     = (analogRead(A0) - pressureZero) * (100 / (pressureMax - pressureZero));
pressureValue     = max(pressureValue, 0.0);
pressureValueInBar= pressureValue * 0.0689476 + 1;
```

---

## 5.2 Flow sensor

This is the hard one. Quoting the 2023 procedure directly:

> This is a difficult sensor to calibrate without a well-known flow. Here we will
> approximate the flow using the choking principle. If the pressure ratio between the
> tank and the outside is two or greater, it can be assumed the flow is choking on the
> small tube. In these cases, the flow rate is equal to the speed of sound
> approximately 343 m/s.

With `Q_tube = A * v`, `A = pi * r^2`, `r = 6.25e-3 m`, `v = 343 m/s`.

**Procedure**

1. Close the pneumatic system and charge to 8 bar. Wire the sensor and check the pins
   against the code.
2. Start the code and be ready to act quickly. Open the valve fast; once the flow is
   fully developed, start the code and let the pressure run out. Reduce the sampling
   time if the flow does not stay high long enough.
3. Insert the calibration factor into the test-setup code.

**The manufacturer's constant is 11 pulses per litre — for water.** The 2023 MATLAB
controller uses 11 and correctly reports **L/hour**:

```matlab
flow_rate = (flow/11) * 60;   % flowrate L/hour
```

The 2024 Arduino firmware uses **7.5** and mislabels the result:

```c
const float calibrationFactor = 7.5;
flowRate = (pulseCount / calibrationFactor) * 60;   // published as "flow_rate"
```

**Neither is right for air.** Both constants are water constants on a water turbine
being used on compressed air, well outside its rated fluid. Recalibrate by the choked
method above before trusting any absolute flow number. See
`docs/06_KNOWN_ISSUES.md` §D2 for the arithmetic error on top of this.

---

## 5.3 Force / load cell

Verbatim procedure:

1. Securely mount the load cell and make sure it is free from any external loads.
2. Apply load *i* to the load cell.
3. Read and record the output value for the applied load.
4. Repeat 2 and 3 for all loads.
5. Calculate the calibration factor by dividing the known loads by the corresponding
   load-cell output values.
6. Update the `calibration factor` value in the Arduino code.

And the closing line of the 2023 document, which is the whole reason this channel
exists:

> **Consider low loads corresponding with the engine torques to enhance accuracy.**

**Status.** The load cells were bought and fitted. `calibration_force.ino` exists in
the shared drive. No firmware in any generation ever published a force reading, and
none of the 2024 data files contain a force column. This is the open gap.

---

## 5.4 Speed

No calibration is needed, but the **resolution** must be understood.

The IR photo interrupter sees a printed disc with **3 lobes**. The Arduino counts
falling edges over one publish period and zeroes the counter each loop.

- Publish period, measured across all 11 runs: **206.6 ms** (4.839 Hz)
- One pulse therefore equals 1/3 revolution in 206.6 ms = **96.8 rpm**
- Every logged speed value is an exact multiple of 20 in the raw files, because the
  firmware divides by an assumed 1 s window. See `docs/06_KNOWN_ISSUES.md` §D1.

**Improving it.** Reprint the interruptor disc with **10 lobes** instead of 3 and
timestamp the publish window, and the resolution goes to about **29 rpm**. Both
changes are small; the disc has no surviving CAD and must be redrawn anyway.

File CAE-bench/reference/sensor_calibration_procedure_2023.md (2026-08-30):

# Sensor calibration — MC/DC experimental pneumatic set-up, IEM

**Authors: Jelmer Veenhuizen & Quentin Hopman, 6 November 2023**

Transcribed from `MCDC_Sensor_calibration_procedure (1).pdf`. Figures omitted.

## 1.1 Pressure sensor

The pressure sensor is calibrated against the atmosphere. Thus the measured value
when the sensor is exposed to the atmosphere corresponds to 1 bar. The spec sheets
indicate a 0.5 % error in output, caused by nonlinear, hysteresis and repeatability.
Therefore, it is assumed that the zeroing against the atmosphere provides accurate
results at 8 bar.

### 1.1.1 Procedure

1. Expose the sensor to the atmosphere by decoupling and closing valves.
2. Connect the sensor to the Arduino/breadboard. Connect black to ground, red to 5 V,
   and green to A0 Arduino. Connect the Arduino to a computer and start Arduino IDE.
3. Run the calibration code provided below.
4. Insert calibrated `pressureZero` and `pressureMax` in the experimental setup code.
5. Connect the sensor to the fire extinguisher pressurized at 8 bar. Measure with
   compressor pneumatic pistol pressure dial. Make sure it is a closed environment.
6. Check if the calibration value is correct. Keep in mind that any difference can be
   caused by multiple things, such as the pressure dial, leaks, incorrect calibration
   etc.

Code: `calibration_pressure.ino` —
https://drive.google.com/file/d/1N5TNWYmDKPXWIamPsnneZvXHBETUde2X/view

## 1.2 Flow sensor

This is a difficult sensor to calibrate without a well-known flow. Here we will
approximate the flow using the choking principle. If the pressure ratio between the
tank and the outside is two or greater, it can be assumed the flow is choking on the
small tube. In these cases, the flow rate is equal to the speed of sound
approximately 343 m/s. This can be supported by a 2D model in Comsol.

The airflow is defined by `Q_tube = A v`, where A is the area of the tube,
`A = pi r^2 = pi (6.25e-3)^2 m^2` and `v = 343 m/s`.

### Procedure

1. Close the pneumatic system and load it to 8 bars. Connect the sensor to the Arduino
   and check the pins in the code against reality.
2. Start the code, get ready to act quickly. Open the valve quick, when the flow is
   fully developed start the code and let the pressure run out. Reduce the sampling
   time if the flow does not stay high long enough.
3. Input the calibration factor into the test setup code.

In this code, the `knownFlowRate` variable is set to your actual known flow rate. The
`calculateCalibrationFactor` function uses this known flow rate, along with the tube
area and speed of sound, to determine the correct calibration factor. Adjust the
values of `knownFlowRate`, `tubeRadius`, and `speedOfSound` based on your specific
setup.

**The manufacturer states that the calibration factor for water should be 11.**

Code: `calibration_flow.ino` —
https://drive.google.com/file/d/1NYfv6ezN-nQ1ZO533Tar7QxmUWB7ZQNv/view

## 1.3 Force sensor

For this calibration, you need the provided weights with masses.

1. Securely mount the load cell and make sure it is free from any external loads.
2. Apply load i to the load cell.
3. Read and record the output value for the applied load.
4. Repeat steps 2 and 3 for all loads.
5. Calculate the calibration factor for the load cell by dividing the known loads by
   the corresponding load cell output values.
6. Update the "calibration factor" value in your Arduino code with the calculated
   calibration factor.

Note: Make sure to replace the placeholder comments with actual known loads and
corresponding load cell outputs. Additionally, ensure that you're using units
consistent with your application (e.g., grams, kilograms, pounds).
**Consider low loads corresponding with the engine torques to enhance accuracy.**

Code: `calibration_force.ino` —
https://drive.google.com/file/d/1Nakx0HwFnjOQpSjgHod1vDwGDWDcIyK0/view

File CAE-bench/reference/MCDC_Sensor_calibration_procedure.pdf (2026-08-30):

# Sensor calibration

## MC/DC Experimental pneumatic set-up

### IEM

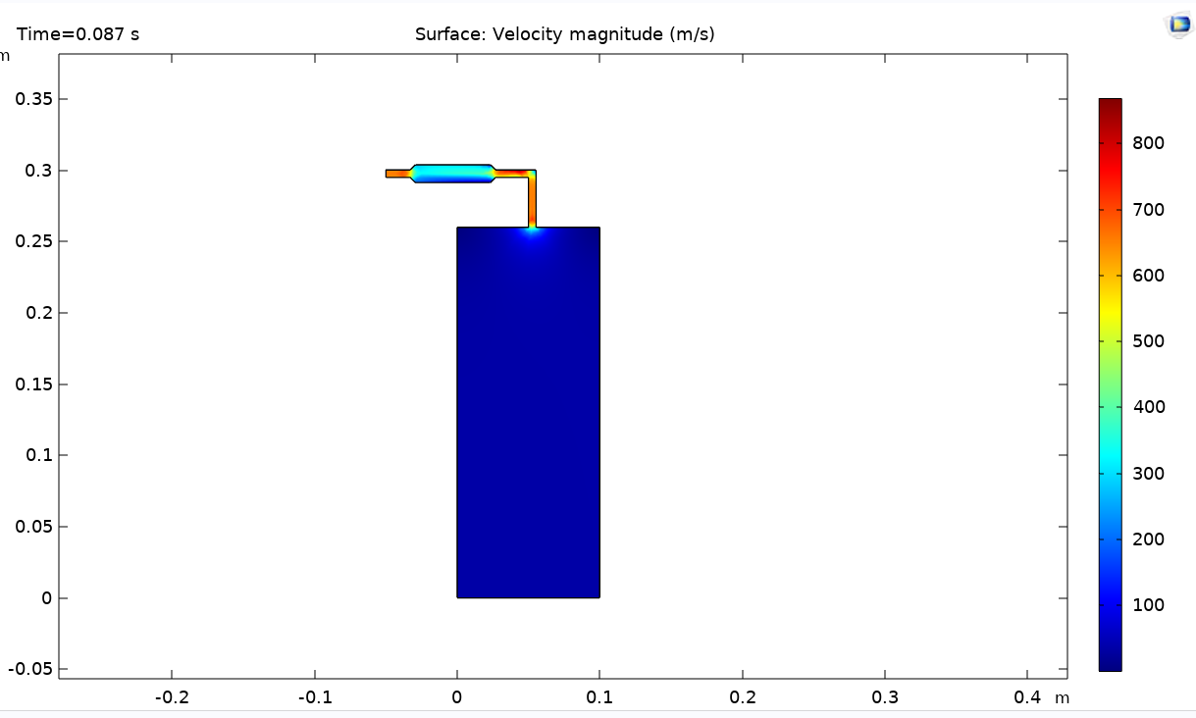
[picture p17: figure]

Authors:
Jelmer Veenhuizen & Quentin Hopman 6 November 2023

## Chapter 1: Sensor calibration

### 1.1 Pressure sensor

The pressure sensor is calibrated against the atmosphere. Thus the measured value when the sensor is exposed to the atmosphere corresponds to 1 bar. The spec sheets indicate a 0.5% error in output, caused by nonlinear, hysteresis and repeatability. Therefore, it is assumed that the zeroing against the atmosphere provides accurate results at 8 bar.

### 1.1.1 Procedure Pressure sensor

1 Expose the sensor to the atmosphere by decoupling and closing valves;

2 Connect the sensor to the Arduino/breadboard. Connect black to ground, red to 5v, and green to A0 Arduino. Connect the Arduino to a computer and start Arduino IDE

3 Run the calibration code provided below

4 Insert calibrated pressureZero and pressureMax in the experimental setup code.

5 Connect the sensor to the fire extinguisher pressurized at 8 bar. Measure with compressor pneumatic pistol pressure dial. Make sure it is a closed environment

6 Check if the calibration value is correct. Keep in mind that any difference can be
caused by multiple things, such as the pressure dial, leaks, incorrect calibration etc.

### 1.1.2 Calibration code pressure sensor

Download code here: https://drive.google.com/file/d/1N5TNWYmDKPXWIamPsnneZvXHBETUde2X/view?usp=sharing (https://drive.google.com/file/d/1N5TNWYmDKPXWIamPsnneZvXHBETUde2X/view?usp=sharing)

2

### 1.2 Flow Sensor

This is a difficult sensor to calibrate without a well-known flow. Here we will approximate the flow using the choking principle. If the pressure ratio between the tank and the outside is two or greater, it can be assumed the flow is choking on the small tube. In these cases, the flow rate is equal to the speed of sound ≈ 343m/s. This can be supported by a 2D model in Comsol. This shows the following velocities.

The manufacturer states that the calibration factor for water should be 11.

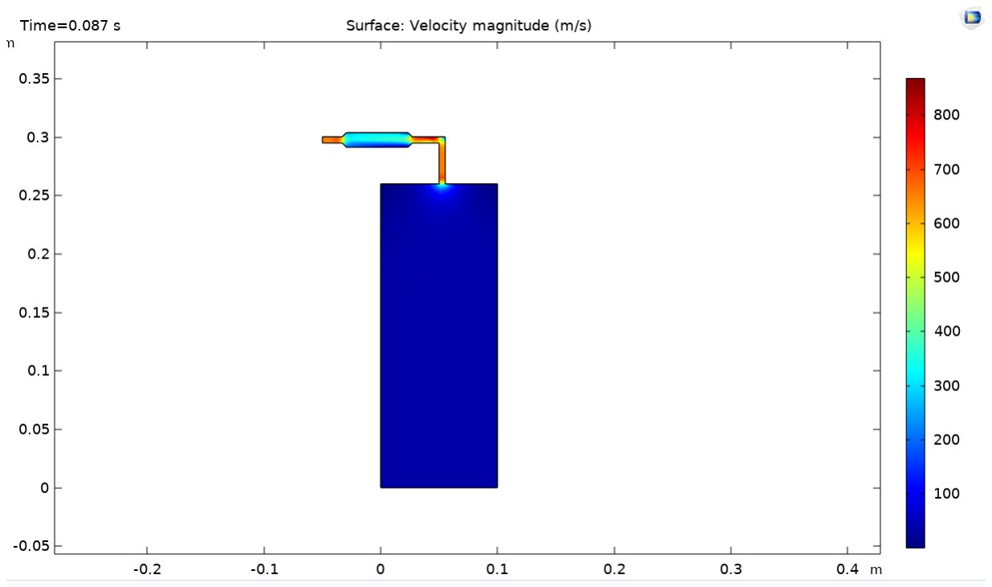
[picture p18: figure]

Figure 1.1: Magnitude of velocity in the tank and tubes.

The airflow is defined by:
Qtube = Av; | (1.1)

Where A is the area of the tube: A = πr² = π(6.25 · 10⁻3)² m² and v = 343 m/s

1 Close the pneumatic system and load it to 8 bars. Connect the sensor to the Arduino and check the pins in the code against reality.

2 Start the code, get ready to act quickly. Open the valve quick, when the flow is fully developed start the code and let the pressure run out. Reduce the sampling time if the flow does not stay high long enough.

3 Input the calibration factor into the test setup code.

### 1.2.1 Code Flow

Download code here: https://drive.google.com/file/d/1NYfv6ezN-nQ1ZO533Tar7QxmUWB7ZQNv/view?usp=sharing (https://drive.google.com/file/d/1NYfv6ezN-nQ1ZO533Tar7QxmUWB7ZQNv/view?usp=sharing)

In this code, the knownFlowRate variable is set to your actual known flow rate. The calculateCalibrationFactor function uses this known flow rate, along with the tube area
and speed of sound, to determine the correct calibration factor. Adjust the values of knownFlowRate, tubeRadius, and speedOfSound based on your specific setup.

3

### 1.3 Force sensor

For this calibration, you need the provided weights with masses (provide these masses).

1 Securely mount the load cell and make sure it is free from any external loads

2 Apply load i to the load cell

3 Read and record the output value for the applied load

4 Repeat steps 2 and 3 for all loads

5 Calculate the calibration factor for the load cell by dividing the known loads by the corresponding load cell output values

6 Update the ”calibration factor” value in your Arduino code with the calculated calibration factor

### 1.3.1 Code Force

Note: Make sure to replace the placeholder comments with actual known loads and corresponding load cell outputs. Additionally, ensure that you’re using units consistent with
your application (e.g., grams, kilograms, pounds). Consider low loads corresponding with
the engine torques to enhance accuracy.

Download code here: https://drive.google.com/file/d/1Nakx0HwFnjOQpSjgHod1vDwGDWDcIyK0/view?usp=sharing (https://drive.google.com/file/d/1Nakx0HwFnjOQpSjgHod1vDwGDWDcIyK0/view?usp=sharing)

4

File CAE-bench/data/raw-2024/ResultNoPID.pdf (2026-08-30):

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

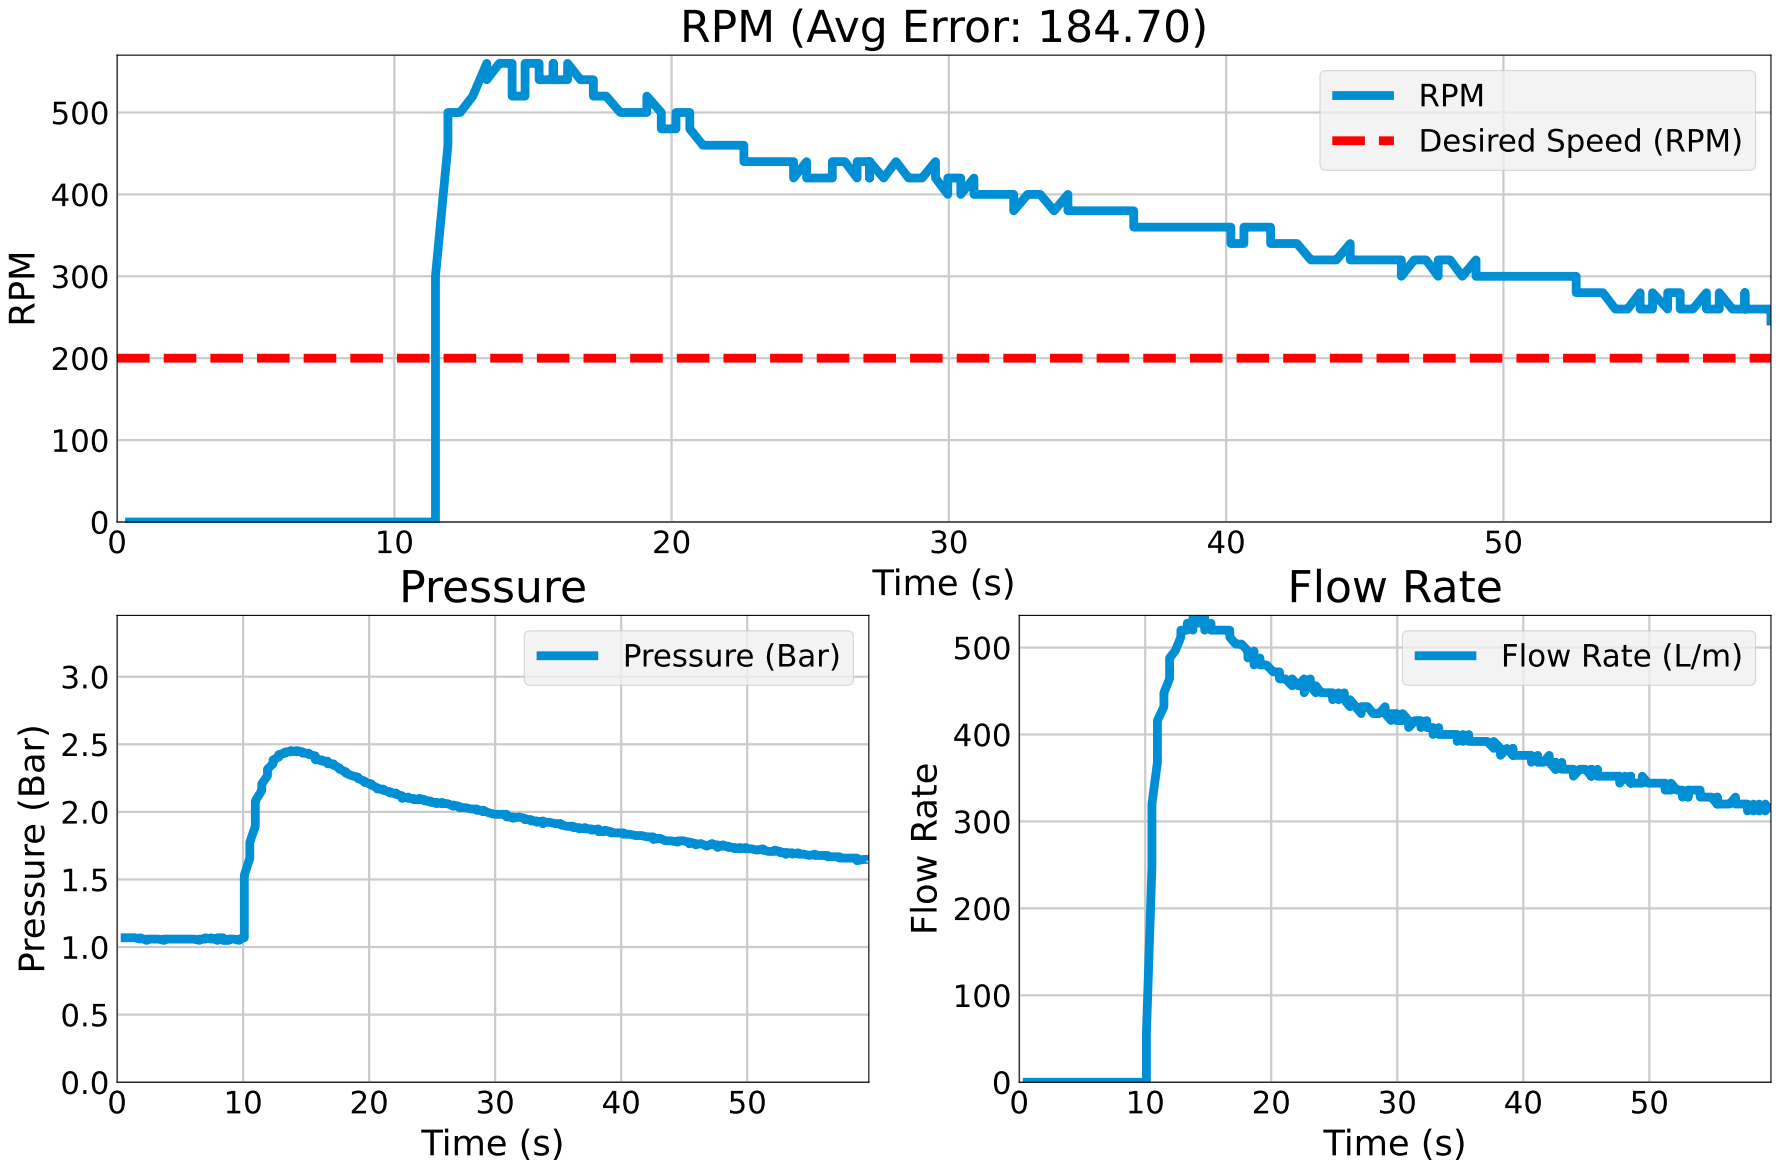
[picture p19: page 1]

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

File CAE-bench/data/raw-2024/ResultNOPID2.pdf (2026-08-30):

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

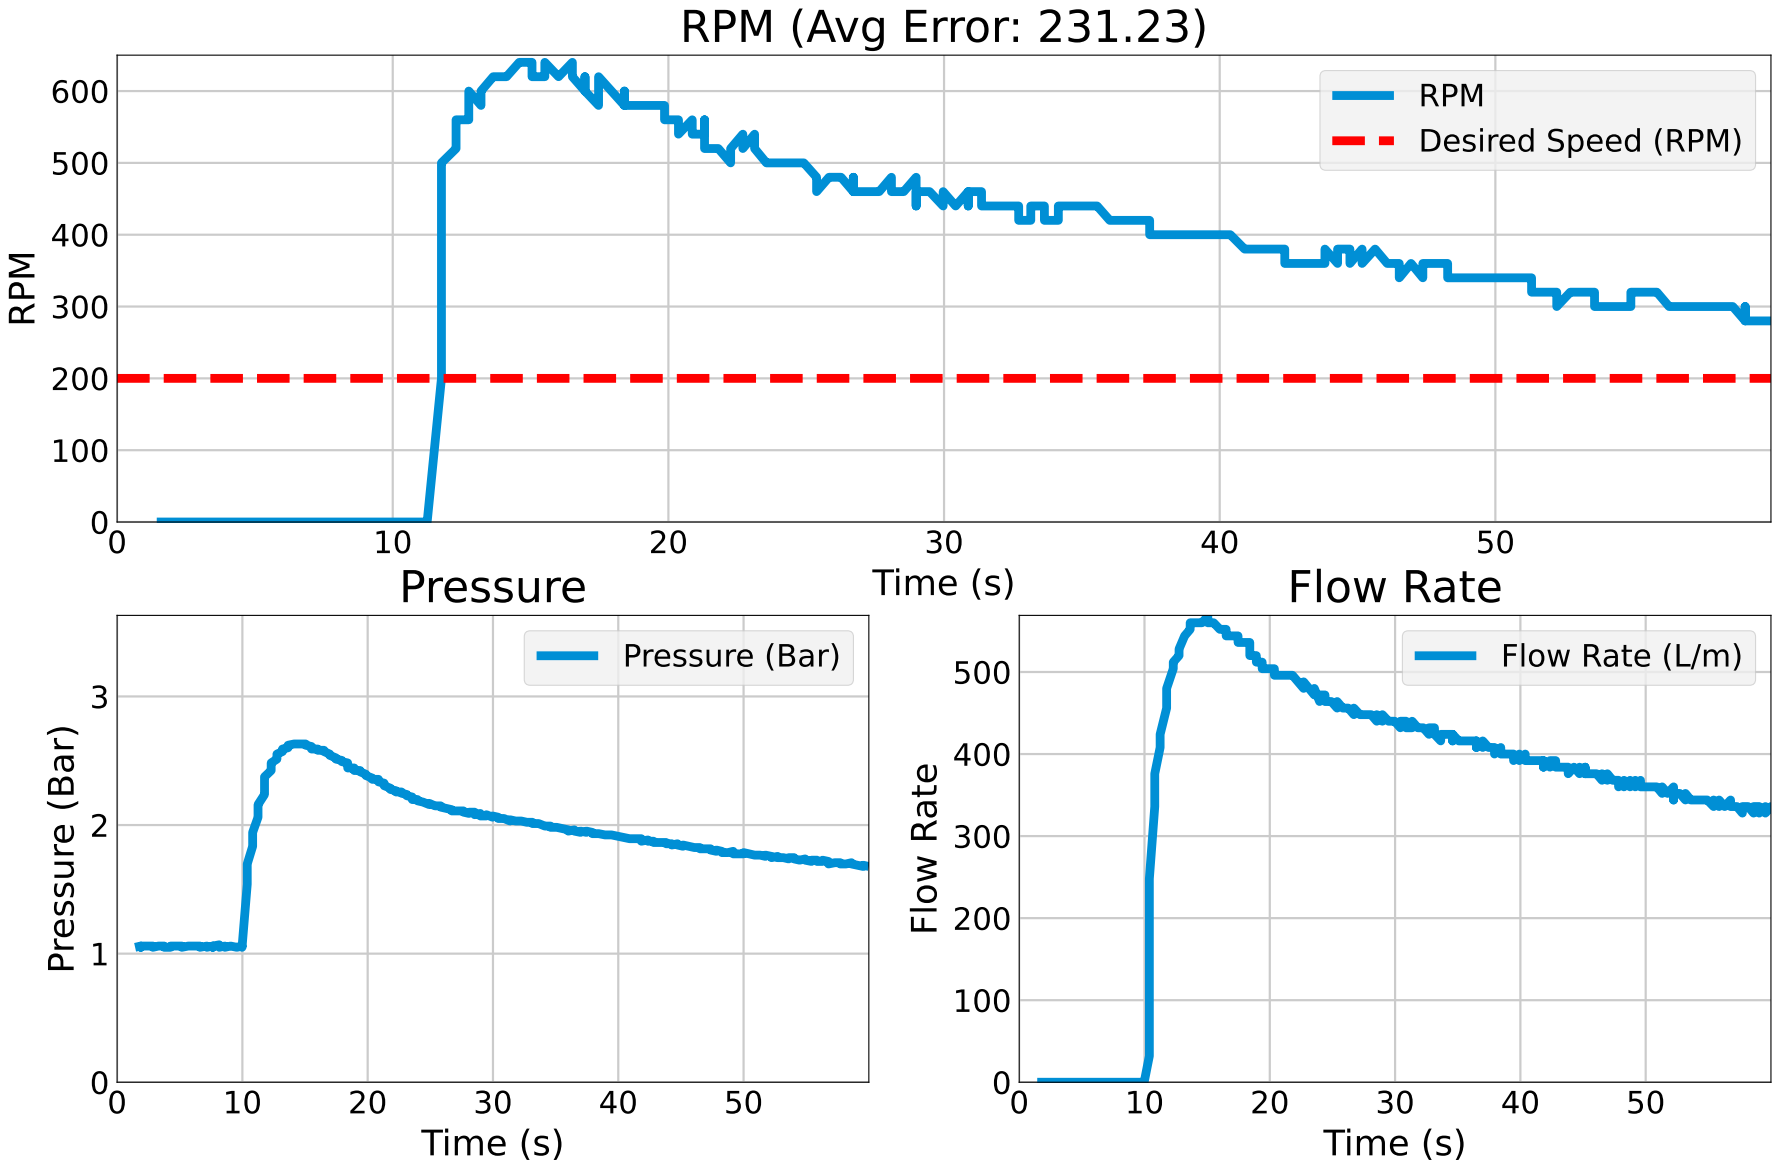
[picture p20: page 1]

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

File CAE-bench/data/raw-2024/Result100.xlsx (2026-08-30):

Time (s) | RPM | Pressure (Bar) | Flow Rate (L/m) | Servo Position
0.2947664261 | 0 | 1.049108 | 0 | 509
0.2947664261 | 0 | 1.049108 | 0 | 494
1.645946026 | 0 | 1.049108 | 0 | 243
1.645946026 | 0 | 1.068751 | 0 | 245
2.152030468 | 0 | 1.05893 | 0 | 253
2.152030468 | 0 | 1.05893 | 0 | 256
2.152030468 | 0 | 1.05893 | 0 | 262
2.632178068 | 0 | 1.05893 | 0 | 273
2.632178068 | 0 | 1.05893 | 0 | 275
3.061993361 | 0 | 1.049108 | 0 | 285
3.061993361 | 0 | 1.05893 | 0 | 286
3.509319305 | 0 | 1.049108 | 0 | 297
3.509319305 | 0 | 1.05893 | 0 | 299
3.993253946 | 0 | 1.049108 | 0 | 310
3.993253946 | 0 | 1.05893 | 0 | 311
3.993253946 | 0 | 1.068751 | 0 | 317
4.534436941 | 0 | 1.049108 | 0 | 329
4.534436941 | 0 | 1.05893 | 0 | 331
4.968619108 | 0 | 1.049108 | 0 | 341
4.968619108 | 0 | 1.05893 | 0 | 342
4.968619108 | 0 | 1.049108 | 0 | 355
5.475290298 | 0 | 1.049108 | 0 | 358
5.475290298 | 0 | 1.049108 | 0 | 362
5.919955254 | 0 | 1.05893 | 0 | 373
5.919955254 | 0 | 1.049108 | 0 | 374
6.356964588 | 0 | 1.068751 | 0 | 385
6.356964588 | 0 | 1.05893 | 0 | 388
6.840281725 | 0 | 1.068751 | 0 | 397
6.840281725 | 0 | 1.05893 | 0 | 400
6.840281725 | 0 | 1.05893 | 0 | 410
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

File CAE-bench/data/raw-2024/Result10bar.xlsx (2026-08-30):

Time (s) | RPM | Pressure (Bar) | Flow Rate (L/m) | Servo Position
1.410255909 | 0 | 9.947474 | 0 | 507
1.896349907 | 0 | 9.957294 | 0 | 237
1.896349907 | 0 | 9.957294 | 0 | 239
1.896349907 | 0 | 9.937652 | 0 | 249
2.486202002 | 0 | 9.947474 | 0 | 253
2.486202002 | 0 | 9.947474 | 0 | 255
2.930768013 | 0 | 9.937652 | 0 | 266
2.930768013 | 0 | 9.947474 | 0 | 268
2.930768013 | 0 | 9.937652 | 0 | 277
3.44943881 | 0 | 9.927831 | 0 | 285
3.44943881 | 0 | 9.908186 | 0 | 286
3.904297113 | 0 | 9.927831 | 0 | 297
3.904297113 | 0 | 9.918008 | 0 | 299
4.379684448 | 0 | 9.898365 | 0 | 310
4.379684448 | 0 | 9.888543 | 0 | 312
4.379684448 | 0 | 9.878722 | 0 | 319
4.879504442 | 0 | 9.888543 | 0 | 327
4.879504442 | 0 | 9.878722 | 0 | 331
5.291100502 | 0 | 9.878722 | 0 | 340
5.291100502 | 0 | 9.878722 | 0 | 342
5.725098372 | 0 | 9.8689 | 0 | 355
5.725098372 | 0 | 9.8689 | 0 | 356
6.161225796 | 0 | 9.888543 | 0 | 366
6.161225796 | 0 | 9.8689 | 0 | 368
6.644075394 | 0 | 9.859078 | 0 | 378
6.644075394 | 0 | 9.849258 | 0 | 381
6.644075394 | 0 | 9.859078 | 0 | 390
7.143601656 | 0 | 9.849258 | 0 | 397
7.143601656 | 0 | 9.829614 | 0 | 400
7.609292507 | 0 | 9.839436 | 0 | 410
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

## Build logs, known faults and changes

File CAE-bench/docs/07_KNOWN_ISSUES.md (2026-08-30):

# 7 — Known issues

Found by auditing the 2024 code against the 11 recorded runs, August 2026. Fix D1 to
D3 before taking any new measurement; they change the numbers.

---

## D1 — CRITICAL. The speed calculation assumes a one-second counting window

The Arduino accumulates IR pulses, publishes them, then zeroes the counter, once per
`delay(200)` loop. Python converts that count to RPM as if it covered a full second.

```
arduinoADC.ino   delay(200);   irPulseCount = 0;
CAEPC.py         rpm = (ir_pulse_count * 60) / 3
measured         4.839 Hz emission -> 206.6 ms window
correction       true rpm = logged rpm x 4.84
```

**Every speed figure in the 2024 report and data is about a fifth of the real speed.**
The nominal "200 rpm" operating point is really about 960 rpm.

Three independent confirmations:

1. Air consumed per revolution. Corrected flow / corrected speed gives 4.3-19 cm3/rev
   against a geometric displacement of 12.5 cm3/shaft-rev. Uncorrected it gives
   260-1140 cm3/rev, 20 to 90 times the displacement, which no engine can do.
2. The bench reference of "about 2700 rpm" used elsewhere matches the corrected
   open-loop plateau of 2655 rpm to within 2 %.
3. The 2023 MATLAB controller computes speed event-based and correctly. The bug was
   introduced by the 2024 rewrite, not inherited.

**Fix.** Timestamp the window instead of assuming it:

```c
// arduinoADC.ino
unsigned long now = micros();
float dt = (now - lastPublish) / 1e6f;
lastPublish = now;
doc["dt_s"] = dt;
```
```python
# CAEPC.py
rpm = (ir_pulse_count / 3) / data['dt_s'] * 60
```

---

## D2 — CRITICAL. Flow carries the same window error, twice over

The YF-S201 family datasheet gives litres per minute as frequency divided by the
pulse constant. The sketch divides a *windowed* count by 7.5 and then multiplies by
60, which converts L/min to L/hour, while the column stays labelled `L/m`.

```
as coded     Q = pulseCount * 8.000
correct      Q = pulseCount * 0.645     (L/min, at a 206.6 ms window)
net          the logged figure is 12.4x the true flow in L/min
peak logged  572 "L/m"  ->  46 L/min  =  2770 L/h
```

On top of the arithmetic there is an unquantified error: the sensor is a **water
turbine used on compressed air**, well outside its rated fluid. Recalibrate.

**Fix.** `flowRate = (pulseCount / dt) / calibrationFactor;   // L/min`

---

## D3 — CRITICAL. Loop gain is divided by the setpoint

```python
servo_position = 200 + ((512 - 200) * pid_output / Desired_Speed)
```

The setpoint sits in the denominator, so the actuator gain moves inversely with it:

| Setpoint | servo units per unit of controller output | relative gain |
|---|---|---|
| 100 | 3.120 | x2.00 |
| 200 | 1.560 | x1.00 (tuned here) |
| 400 | 0.780 | x0.50 |

The report reads the resulting behaviour as a property of the engine — over-damped at
100 rpm, under-damped at 400. It is the controller detuning itself.

**Fix.** `servo_position = 200 + SERVO_SPAN * pid_output` with `SERVO_SPAN` fixed, and
let the gains carry the tuning. One gain set then holds across the range.

---

## D4 — MAJOR. Integral and derivative have no timestep

`integral += error` and `derivative = error - previous_error` are per-sample, not
per-second. At the measured 4.84 Hz the effective integral gain is 0.097 per second,
not the 0.02 written in the file. Change the Arduino delay, the baud rate or the PC
and the tuning moves with it.

**Fix.** Scale both by the measured `dt` from D1.

---

## D5 — MAJOR. The integrator winds up against a clamped actuator

`set_servo_position` clamps to 200-512 but the integral keeps accumulating with no
anti-windup and no limit. This is the mechanism behind the sustained oscillation in
the 100 rpm run, where the valve reaches its closed stop and the controller has to
unwind before it can respond.

**Fix.** Freeze the integral whenever the command is clamped.

---

## D6 — MINOR. Timestamps are frame times, not sample times

Serial lines are drained inside a matplotlib animation callback, so every sample read
in one frame gets the same timestamp. 284 samples share about 127 distinct stamps, in
bursts of up to three. Any derivative or spectral analysis inherits that jitter.

**Fix.** Stamp each sample when it is parsed, not once per frame.

---

## D7 — MINOR. The derivative term does nothing

With speed quantised to 20 logged units and Kd = 0.0003, a one-step change contributes
0.006 servo units, four orders of magnitude below the 0.5-unit servo deadband. Call it
a PI controller so whoever tunes it next has the right expectation.

---

## T — The torque channel: built twice, logged zero times

| Evidence | Where |
|---|---|
| Printed friction brake, 11 parts | shared drive, folder `torquemeter`, Dec 2023 |
| Brake firmware, 3 versions | `torquemotor1/2/3.ino`, Oct 2023 |
| Load-cell calibration procedure and sketch | `calibration_force.ino`, Nov 2023 |
| 2 x load cell 500 g / 1 kg, bought and fitted | Aart's BOM, 2024 |
| Load-cell attachment, printed, qty 2 | Aart's BOM, 2024 |
| **Any force column in any data file** | **none** |
| **Any torque figure in any report** | **none** |

Both 2023 reports list load torque as future work. Aart's discussion says back
pressure was a starting goal and the focus shifted. The hardware is there; the
acquisition never was. Adding one analog channel closes it.

Note also that the **load-cell attachment bracket has no CAD anywhere**, so it must be
redrawn before the channel can be rebuilt.

---

## Two documentation errors worth fixing at source

**Screw size.** The report says the servo bracket uses "4 4-m2-screws". The holes in
`CAEfinal.STL` are Ø3.96 mm, which is M4 clearance.

**Print settings.** Table II of the report quotes 70 % infill, 4 mm infill line
distance and 50 mm/s. Those are the values on the *right* extruder, which prints PVA
support. The part is on the left extruder at **100 % infill and 15 mm/s**. The quoted
17 h 42 print time is only consistent with the latter.

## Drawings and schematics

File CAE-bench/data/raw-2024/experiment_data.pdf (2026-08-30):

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

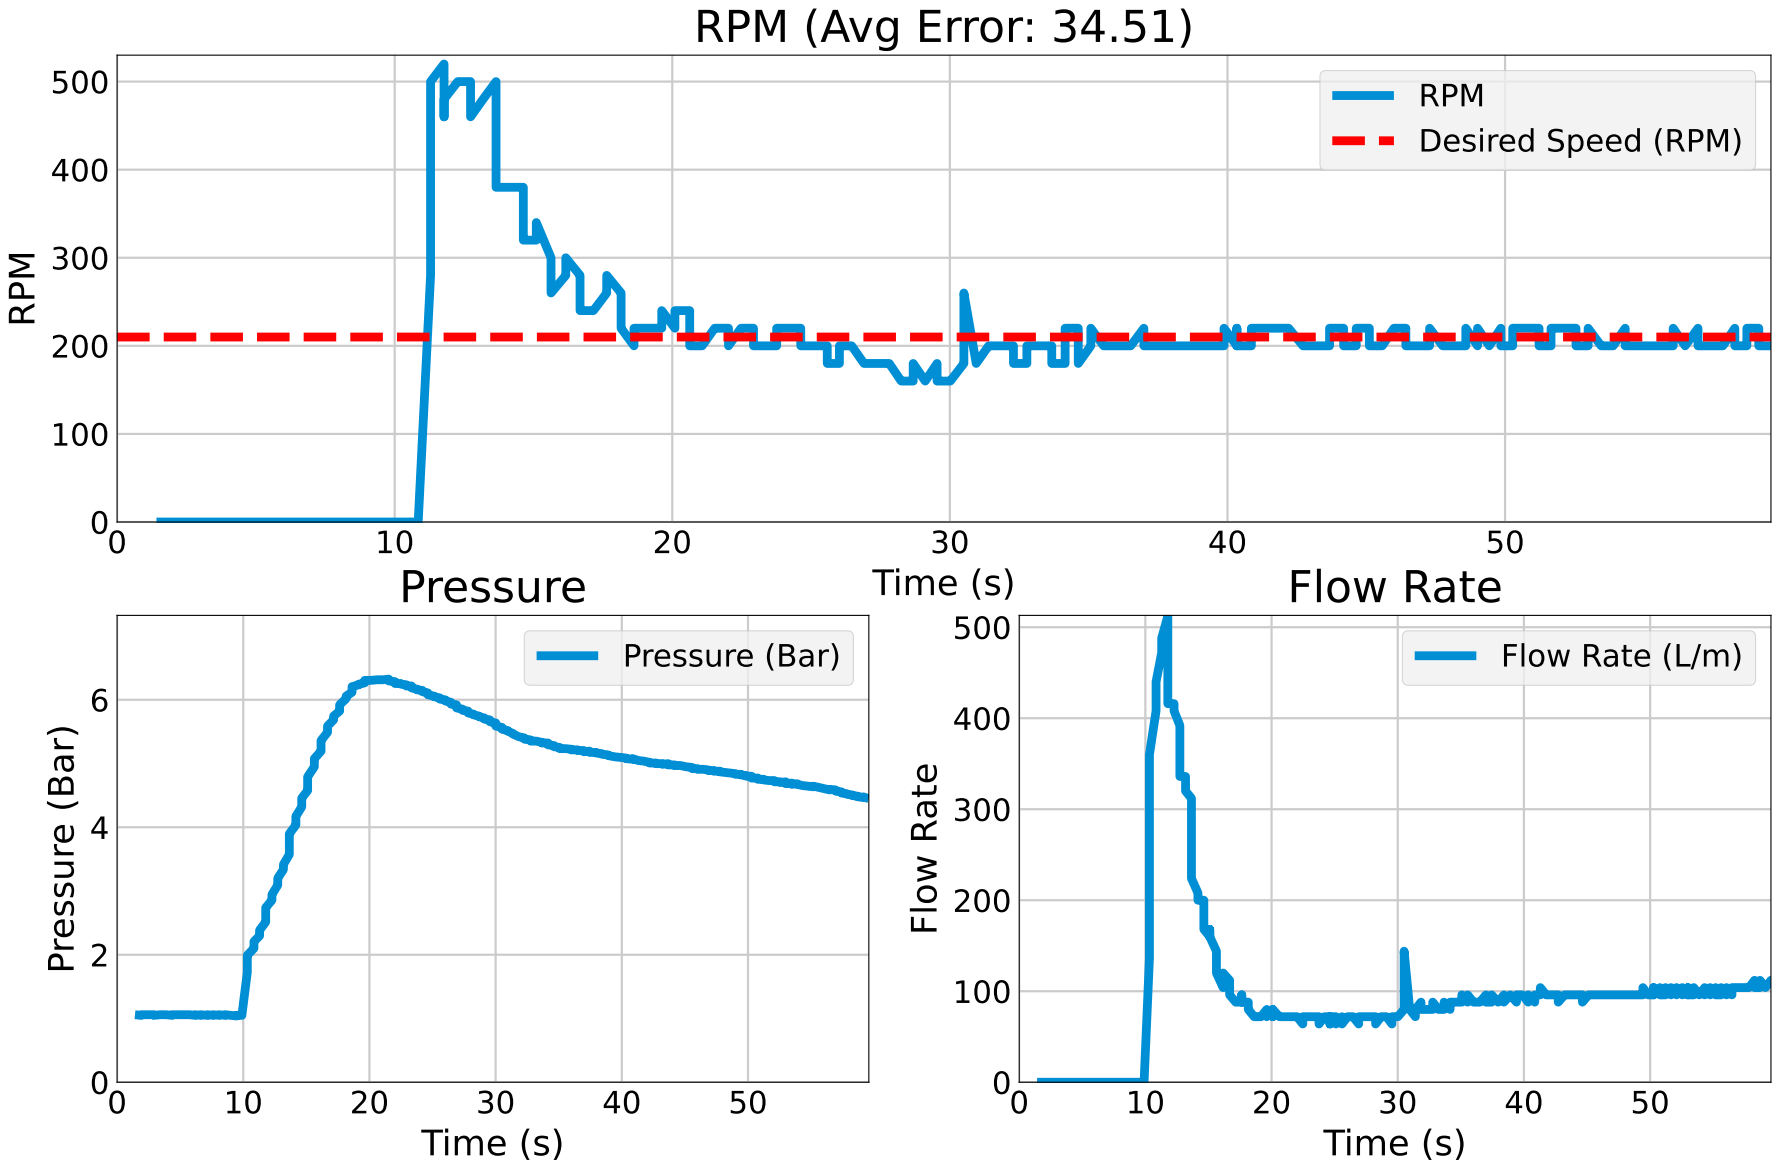
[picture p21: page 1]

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

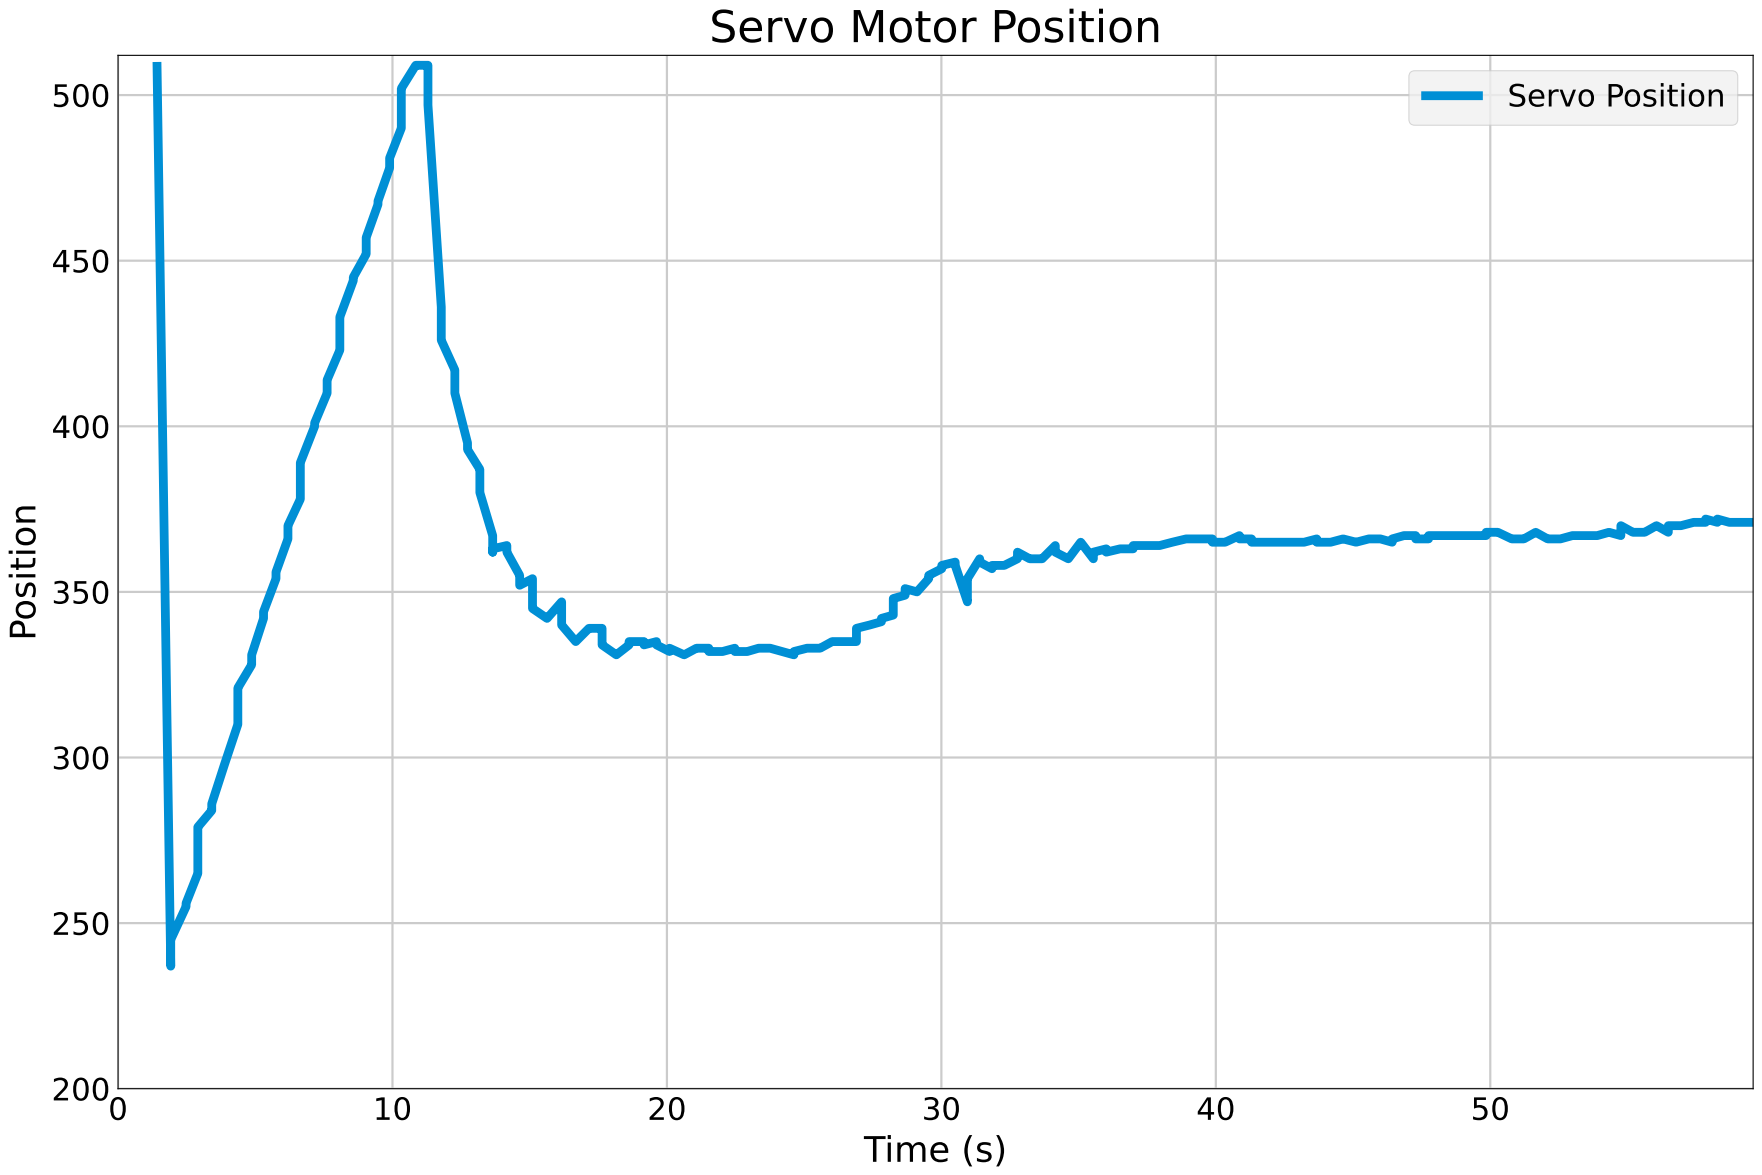
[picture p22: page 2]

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

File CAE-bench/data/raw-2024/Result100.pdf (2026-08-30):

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

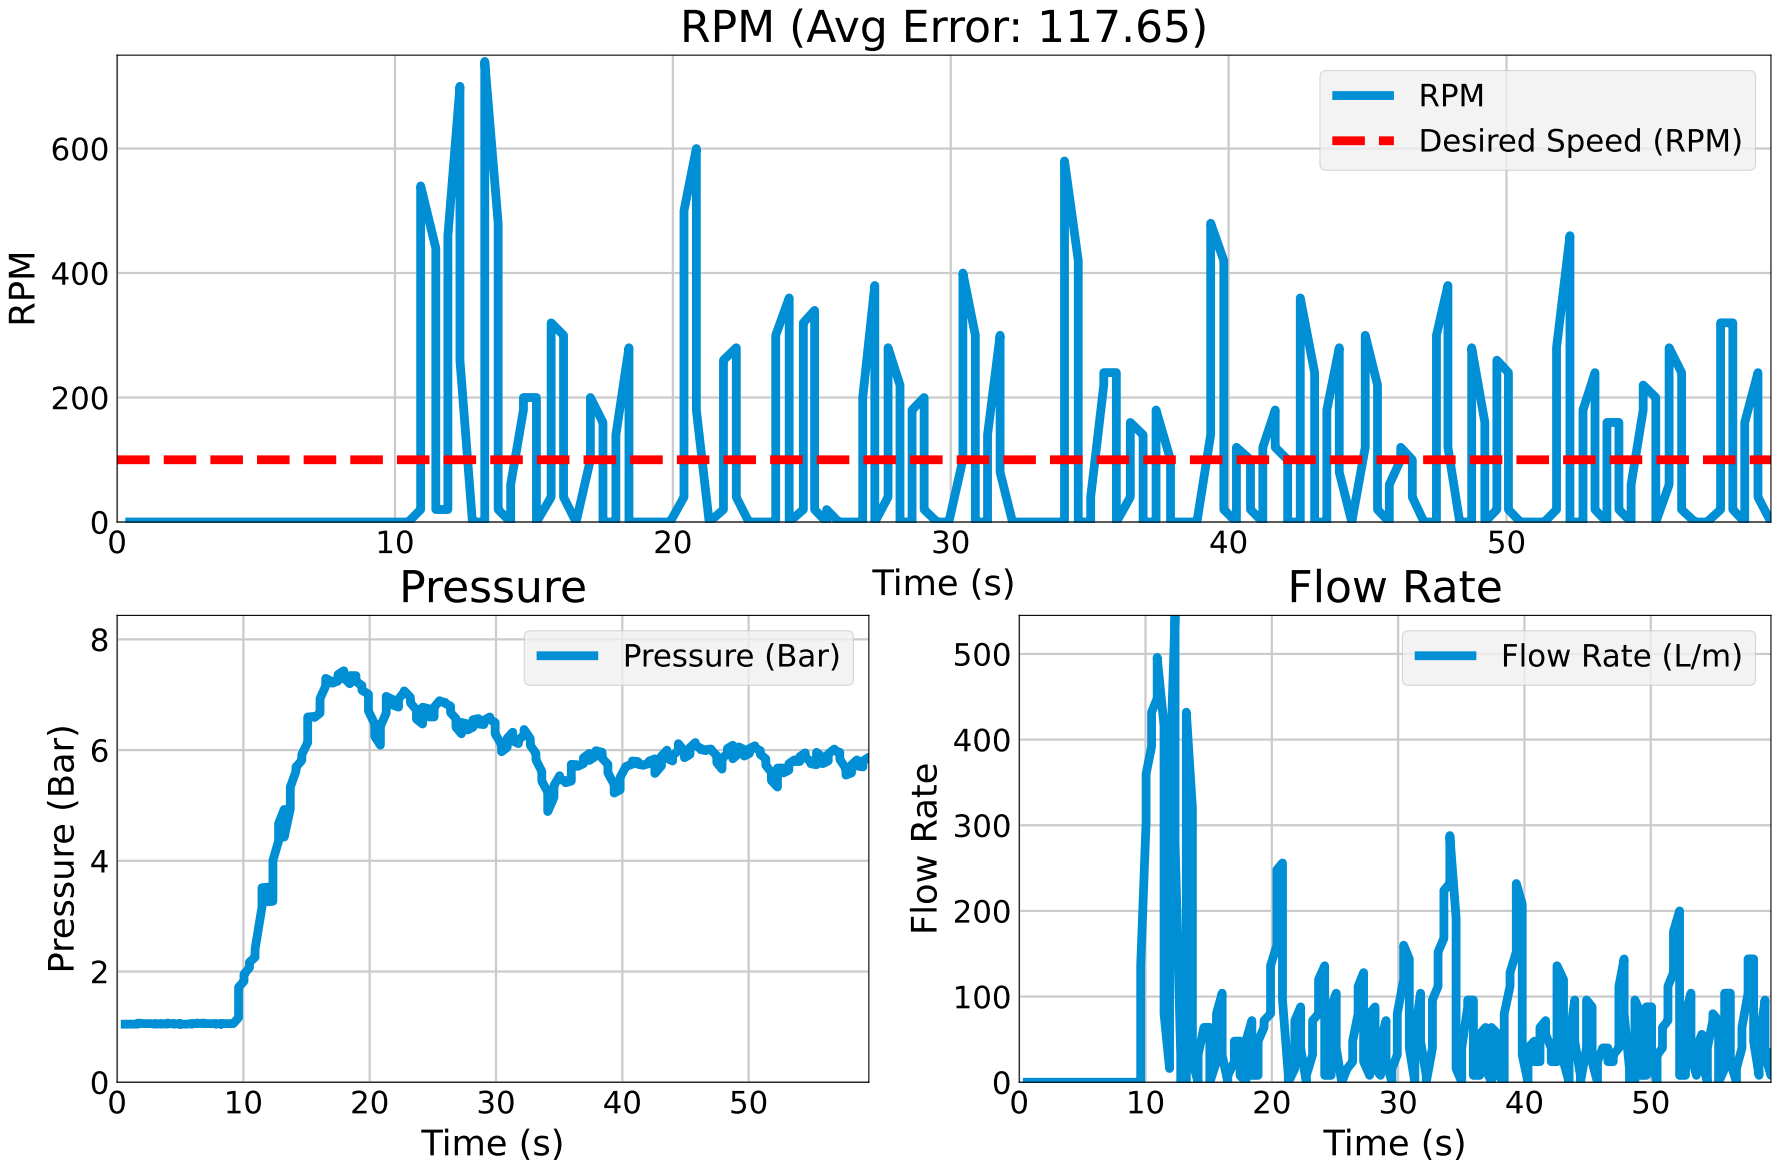
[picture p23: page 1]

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

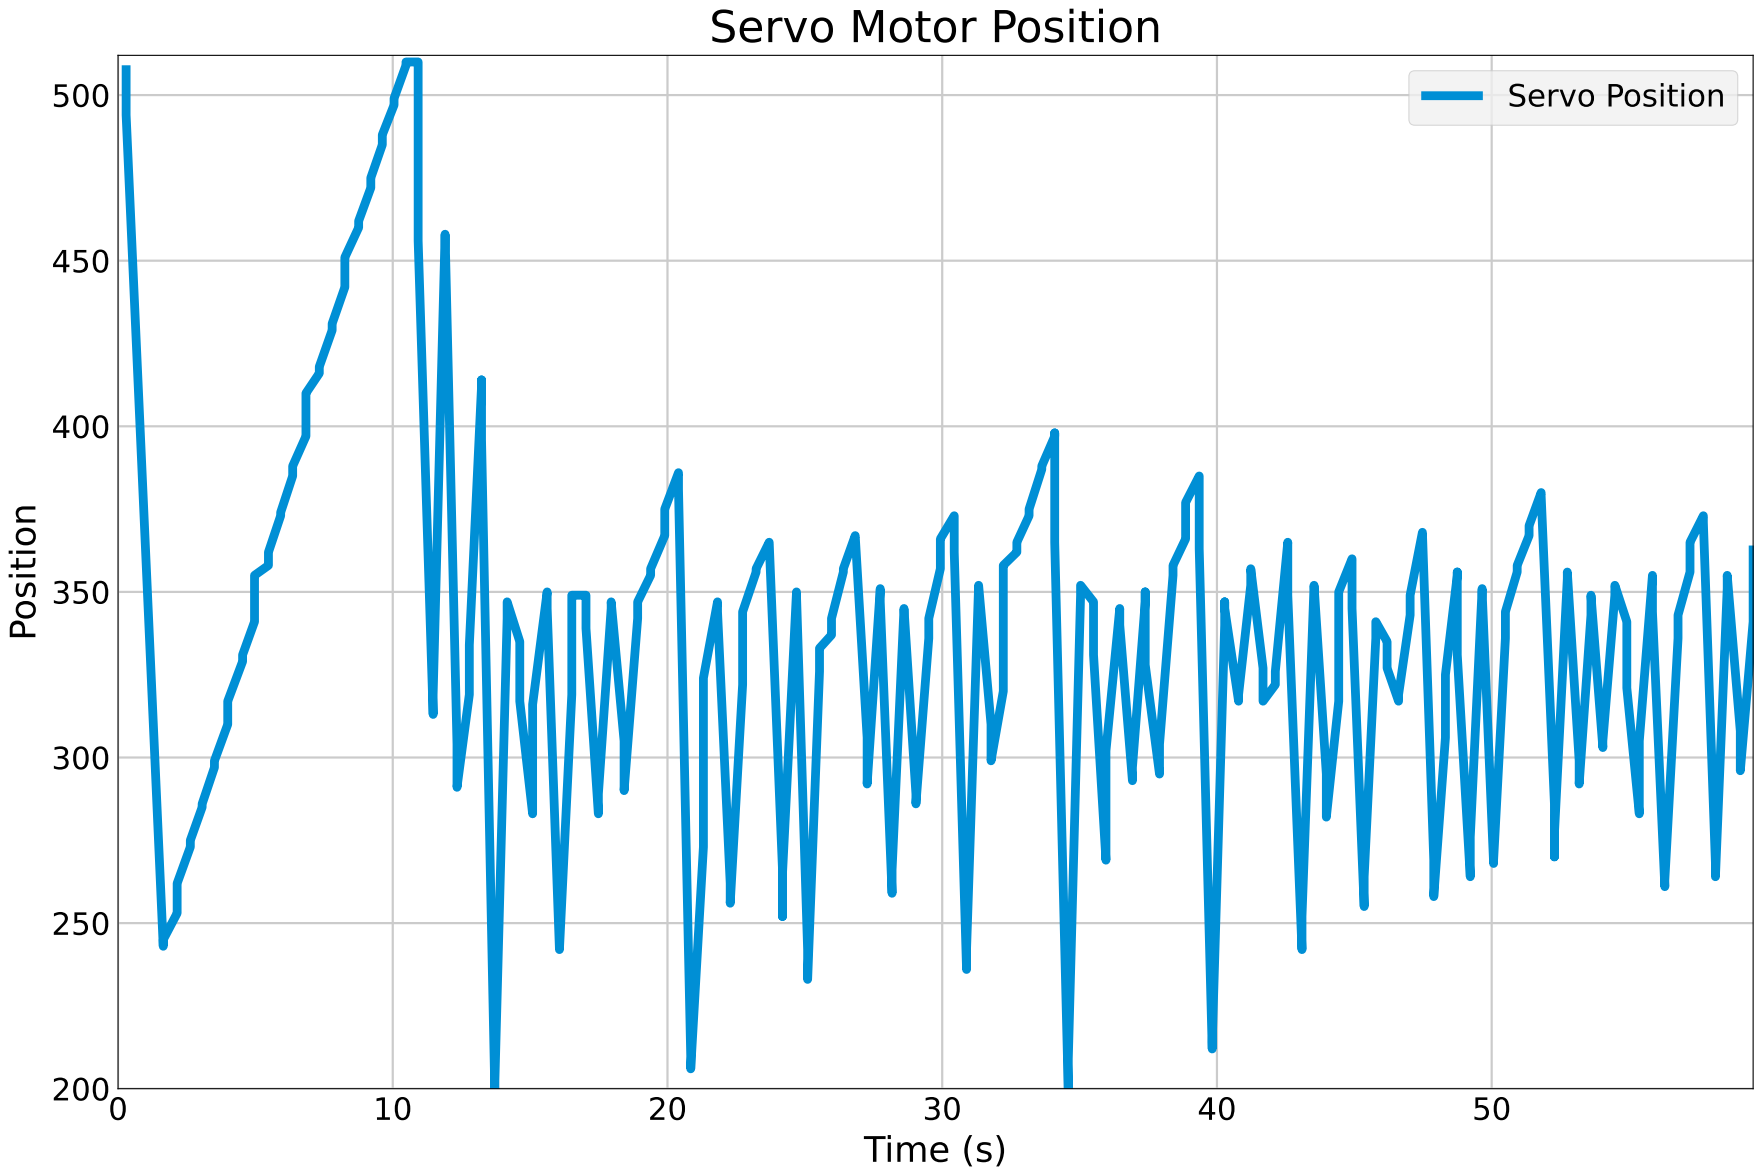
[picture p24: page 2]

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

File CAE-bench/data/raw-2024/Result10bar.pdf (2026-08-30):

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

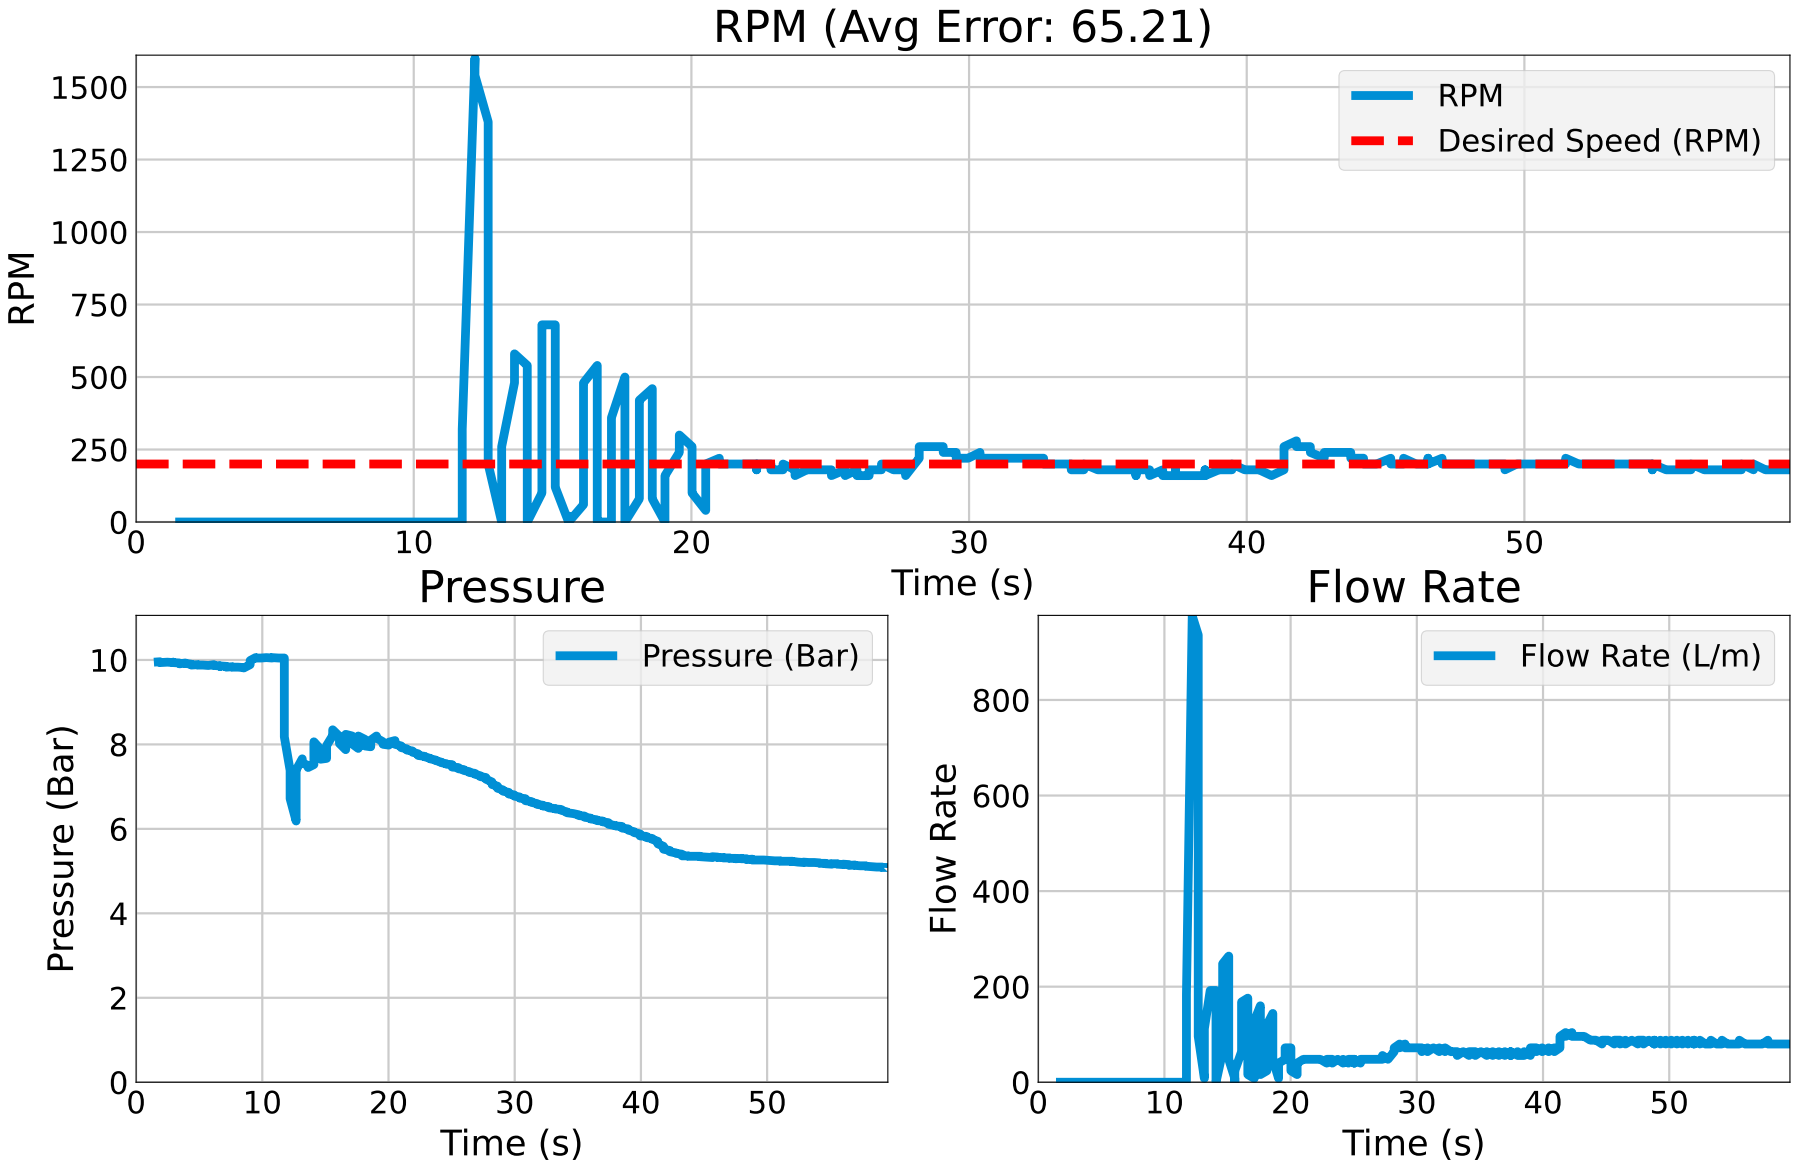
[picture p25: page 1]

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

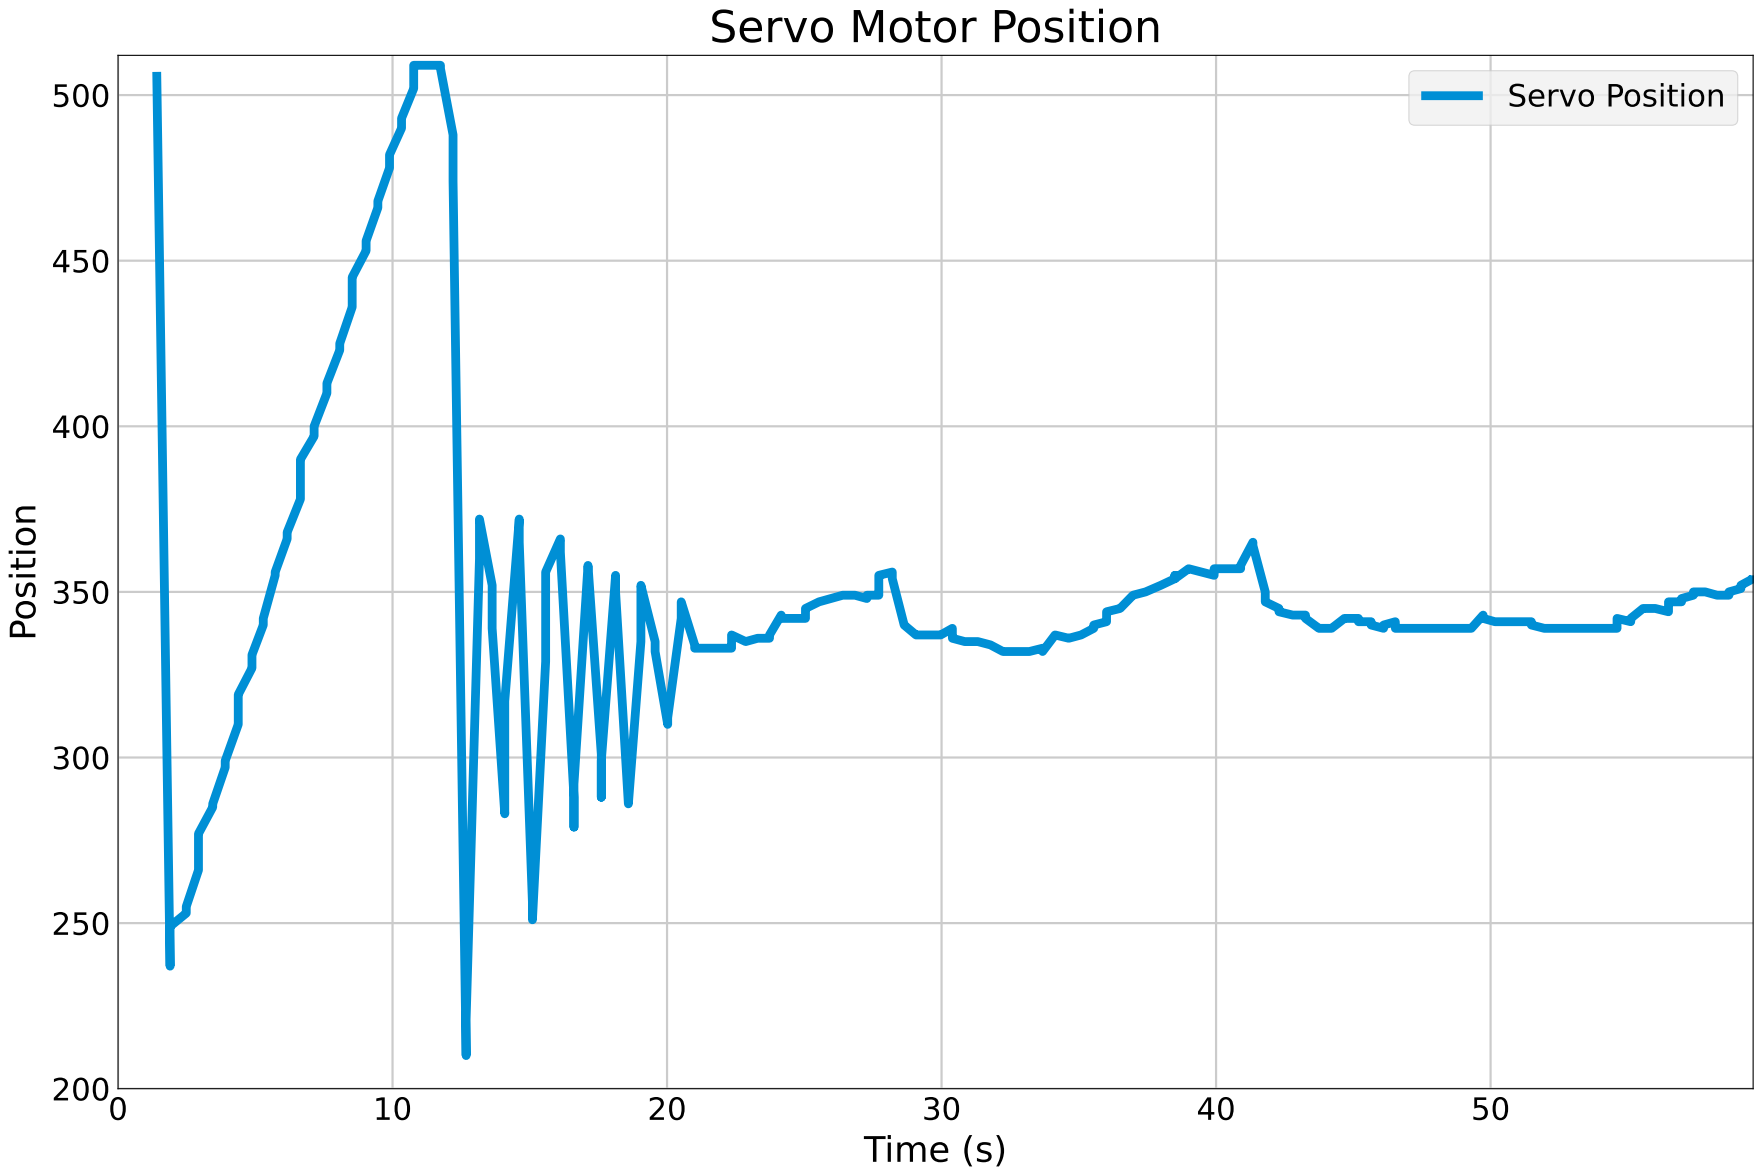
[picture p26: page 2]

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

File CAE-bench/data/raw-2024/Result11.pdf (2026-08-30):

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

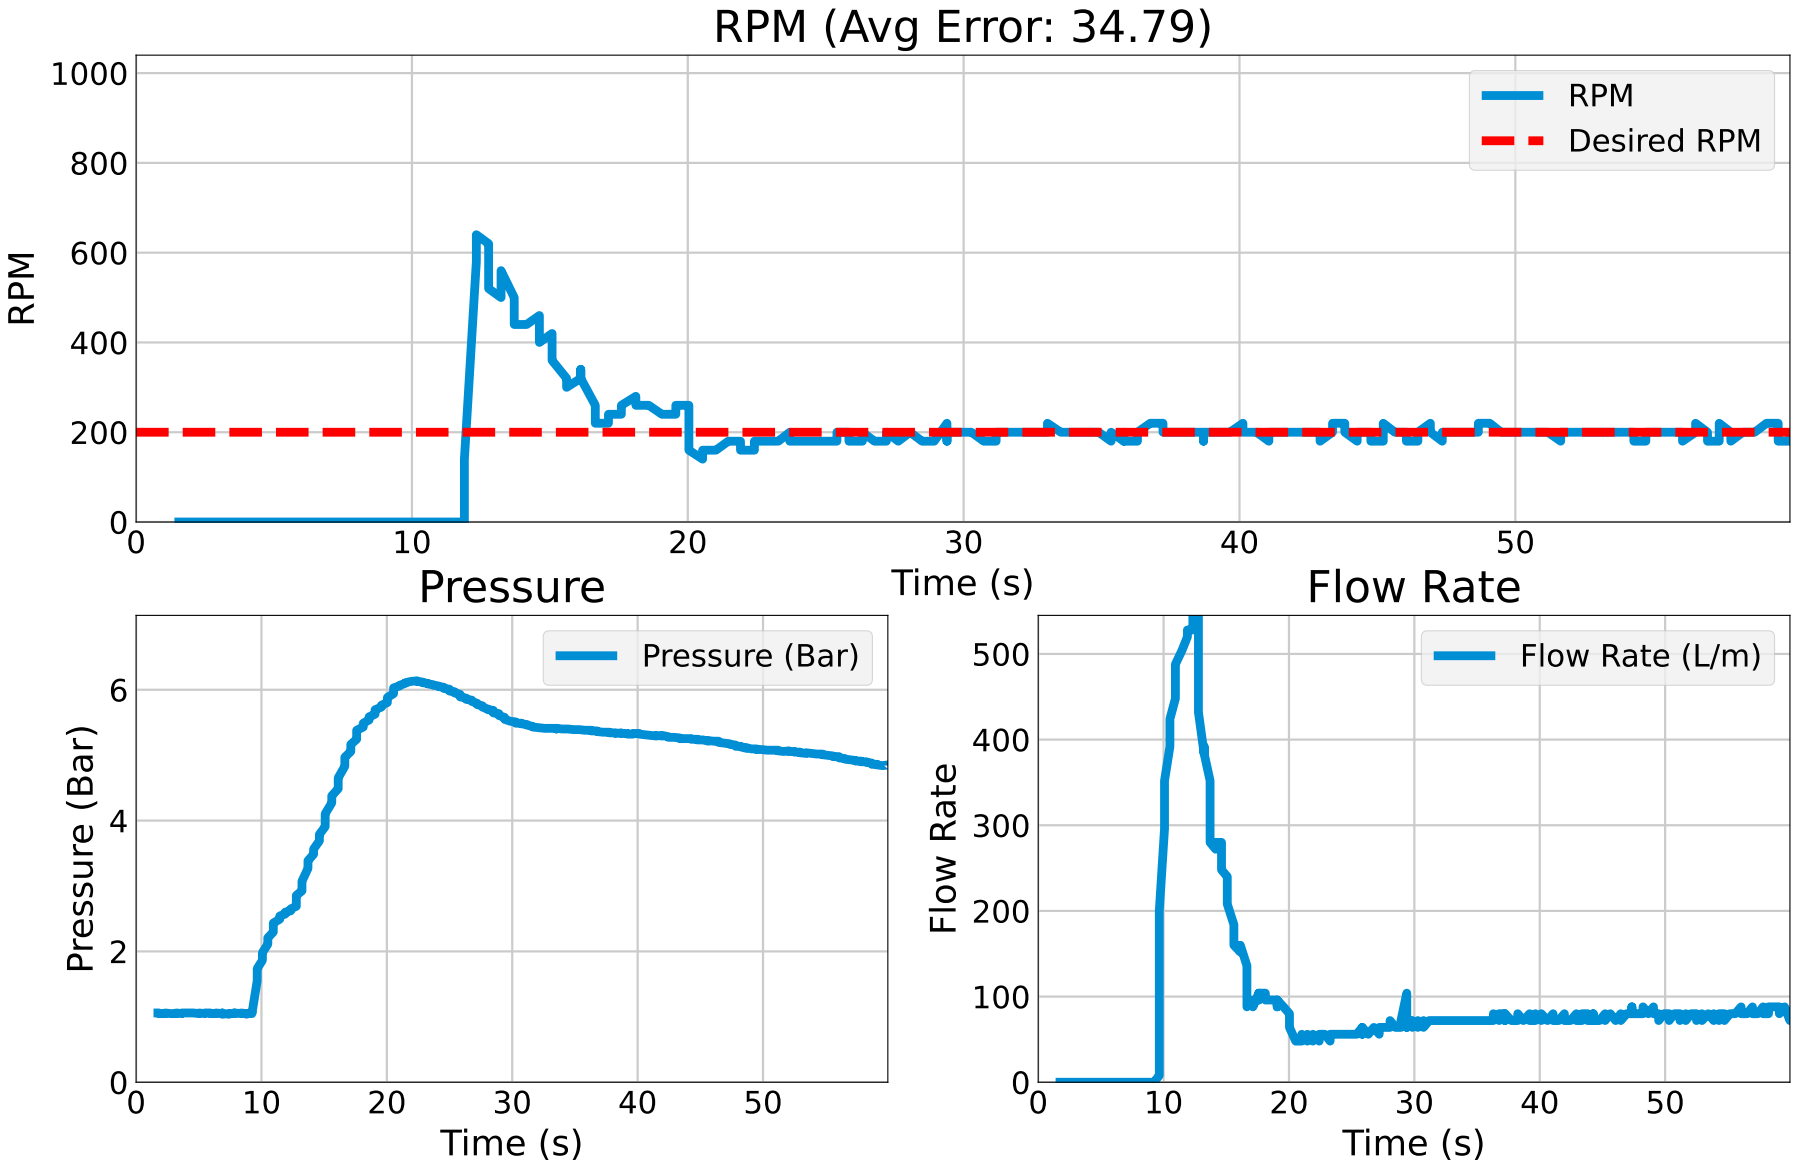
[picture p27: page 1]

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

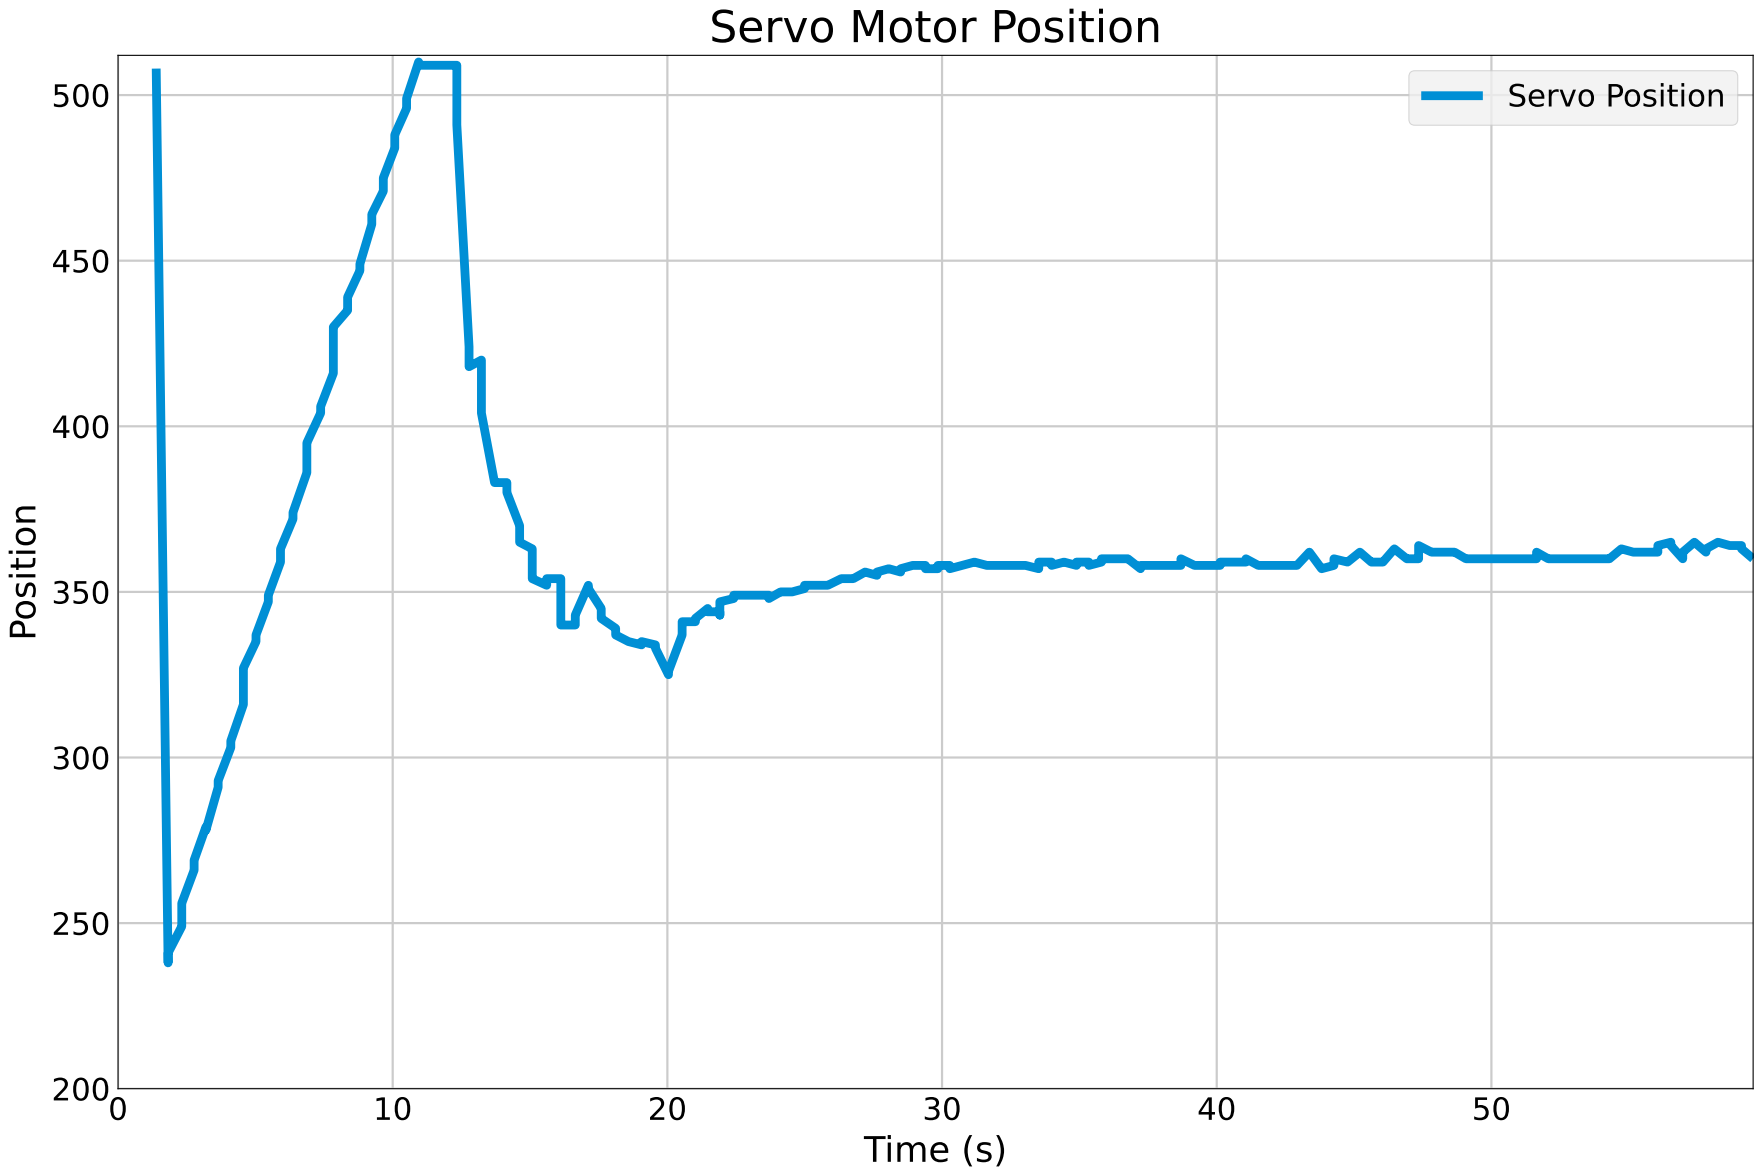
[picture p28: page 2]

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

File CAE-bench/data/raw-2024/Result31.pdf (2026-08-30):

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

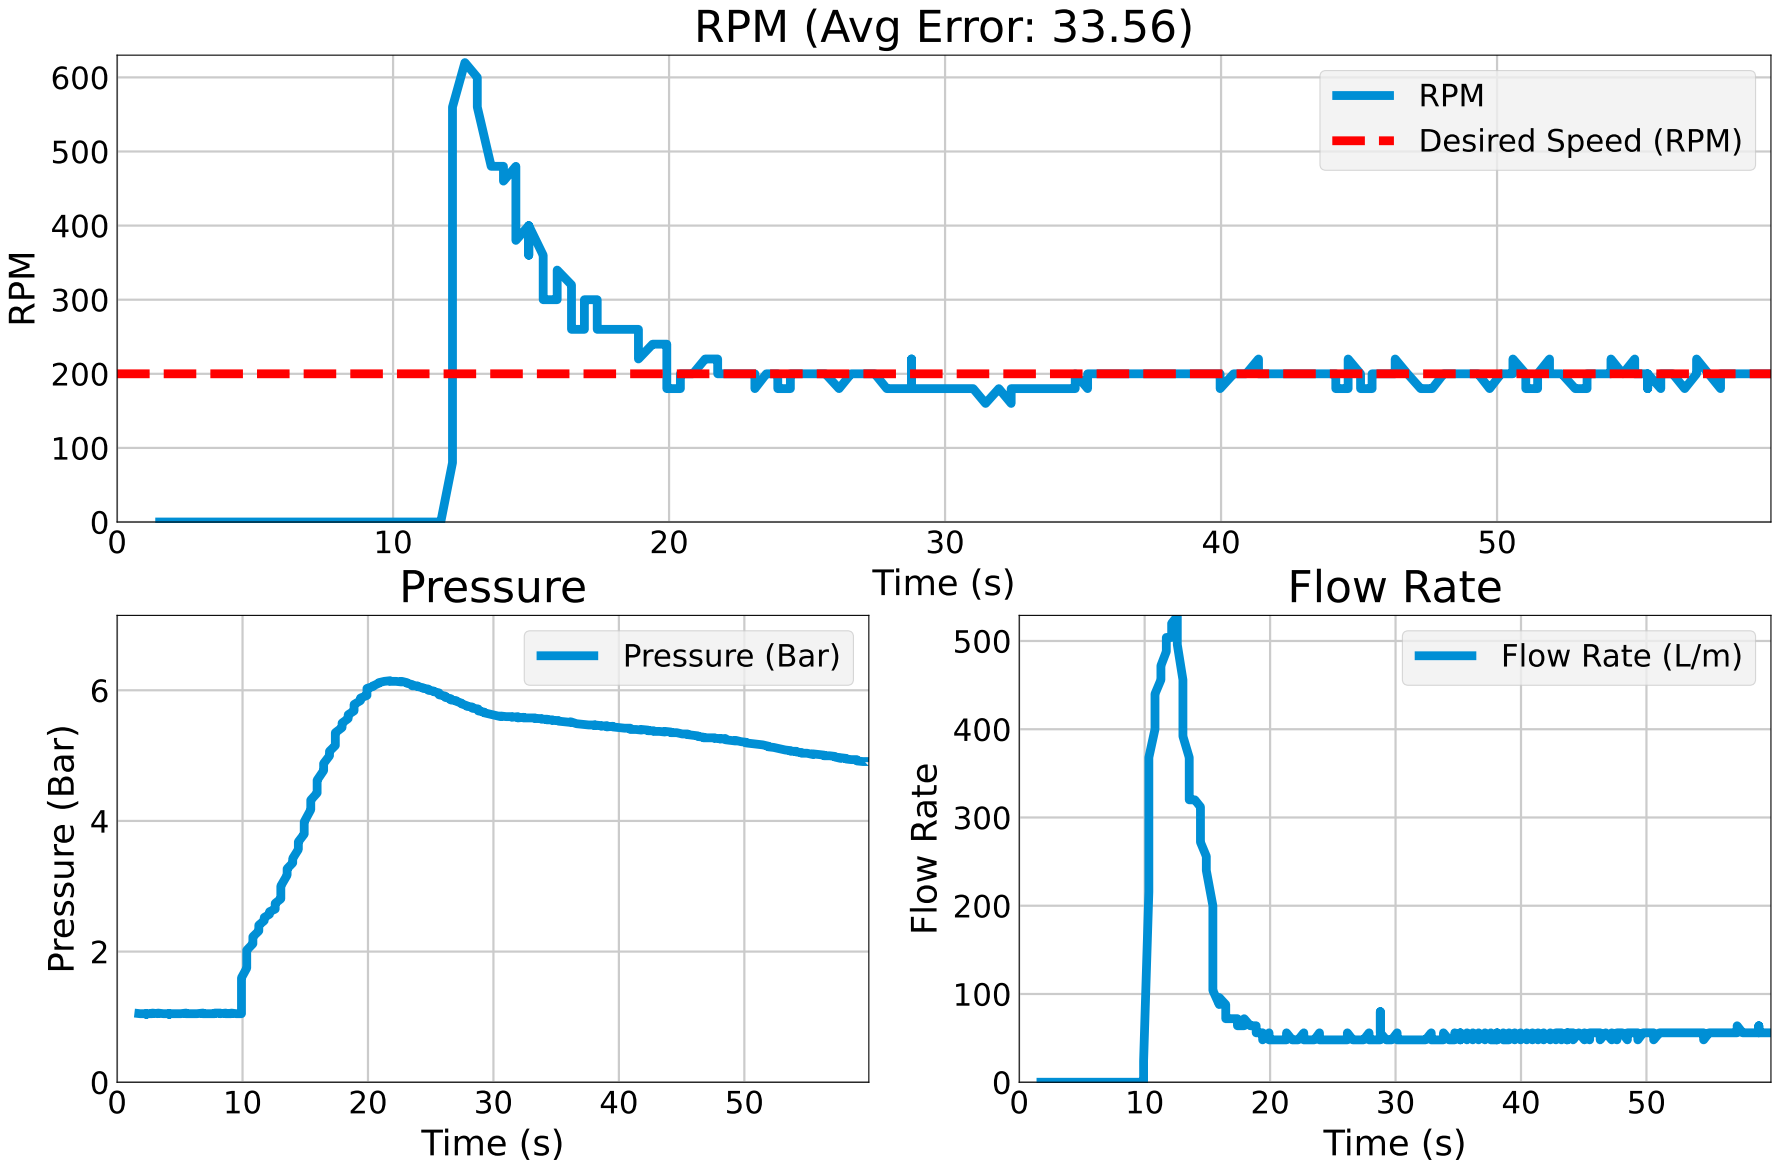
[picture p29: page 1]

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

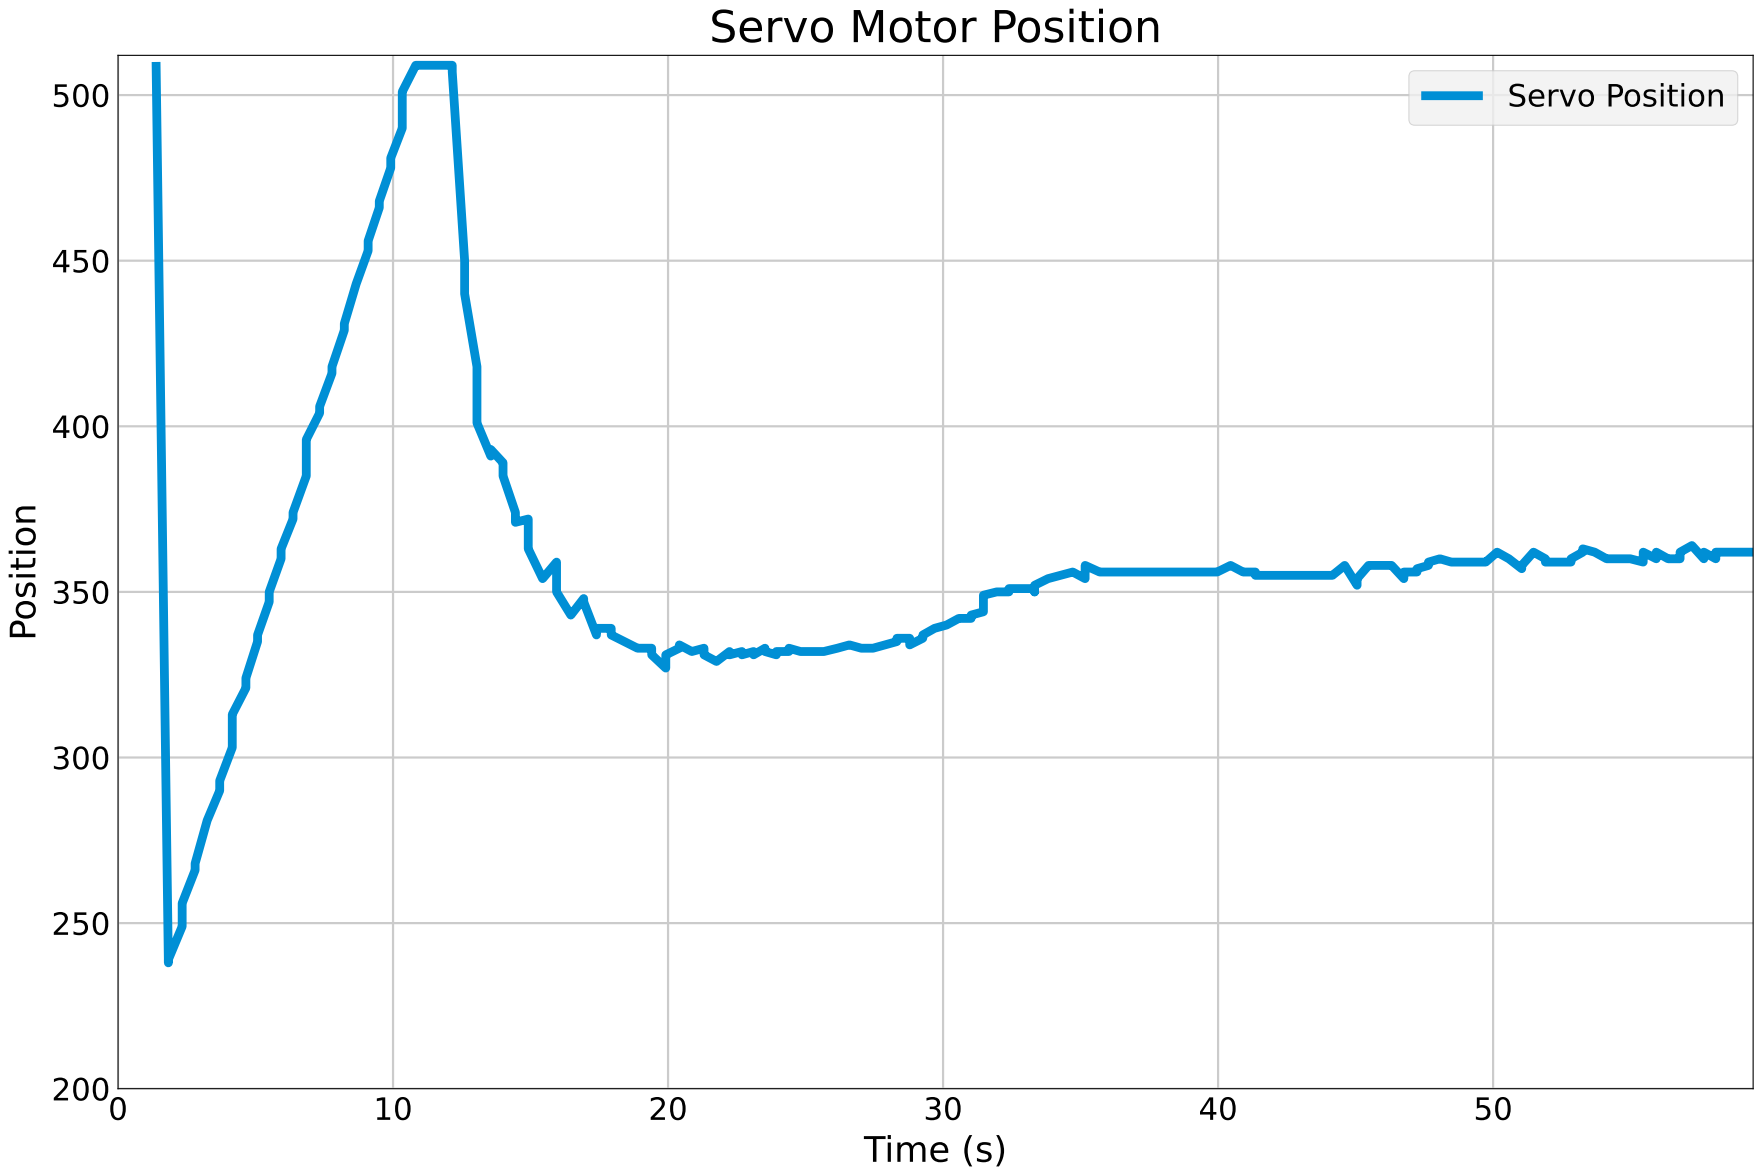
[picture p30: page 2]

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

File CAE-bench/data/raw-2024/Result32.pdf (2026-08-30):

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

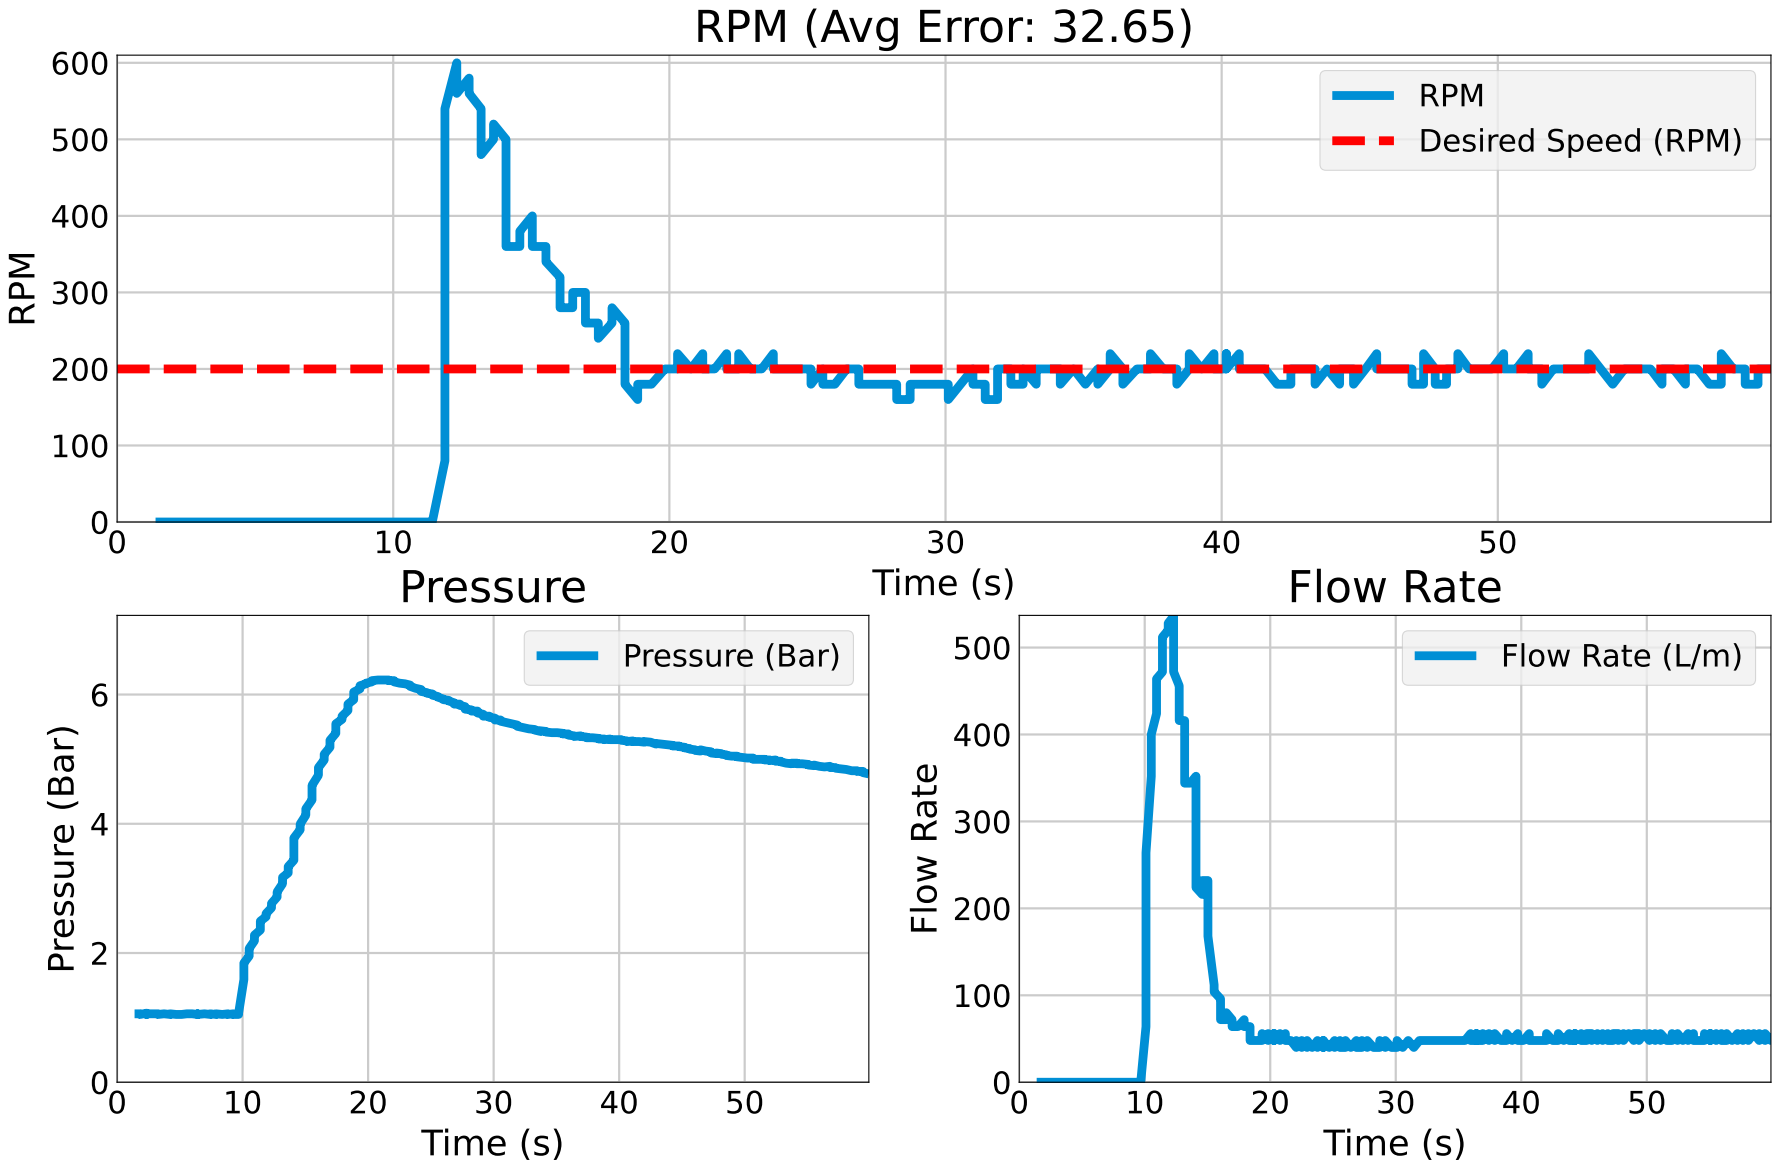
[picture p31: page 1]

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

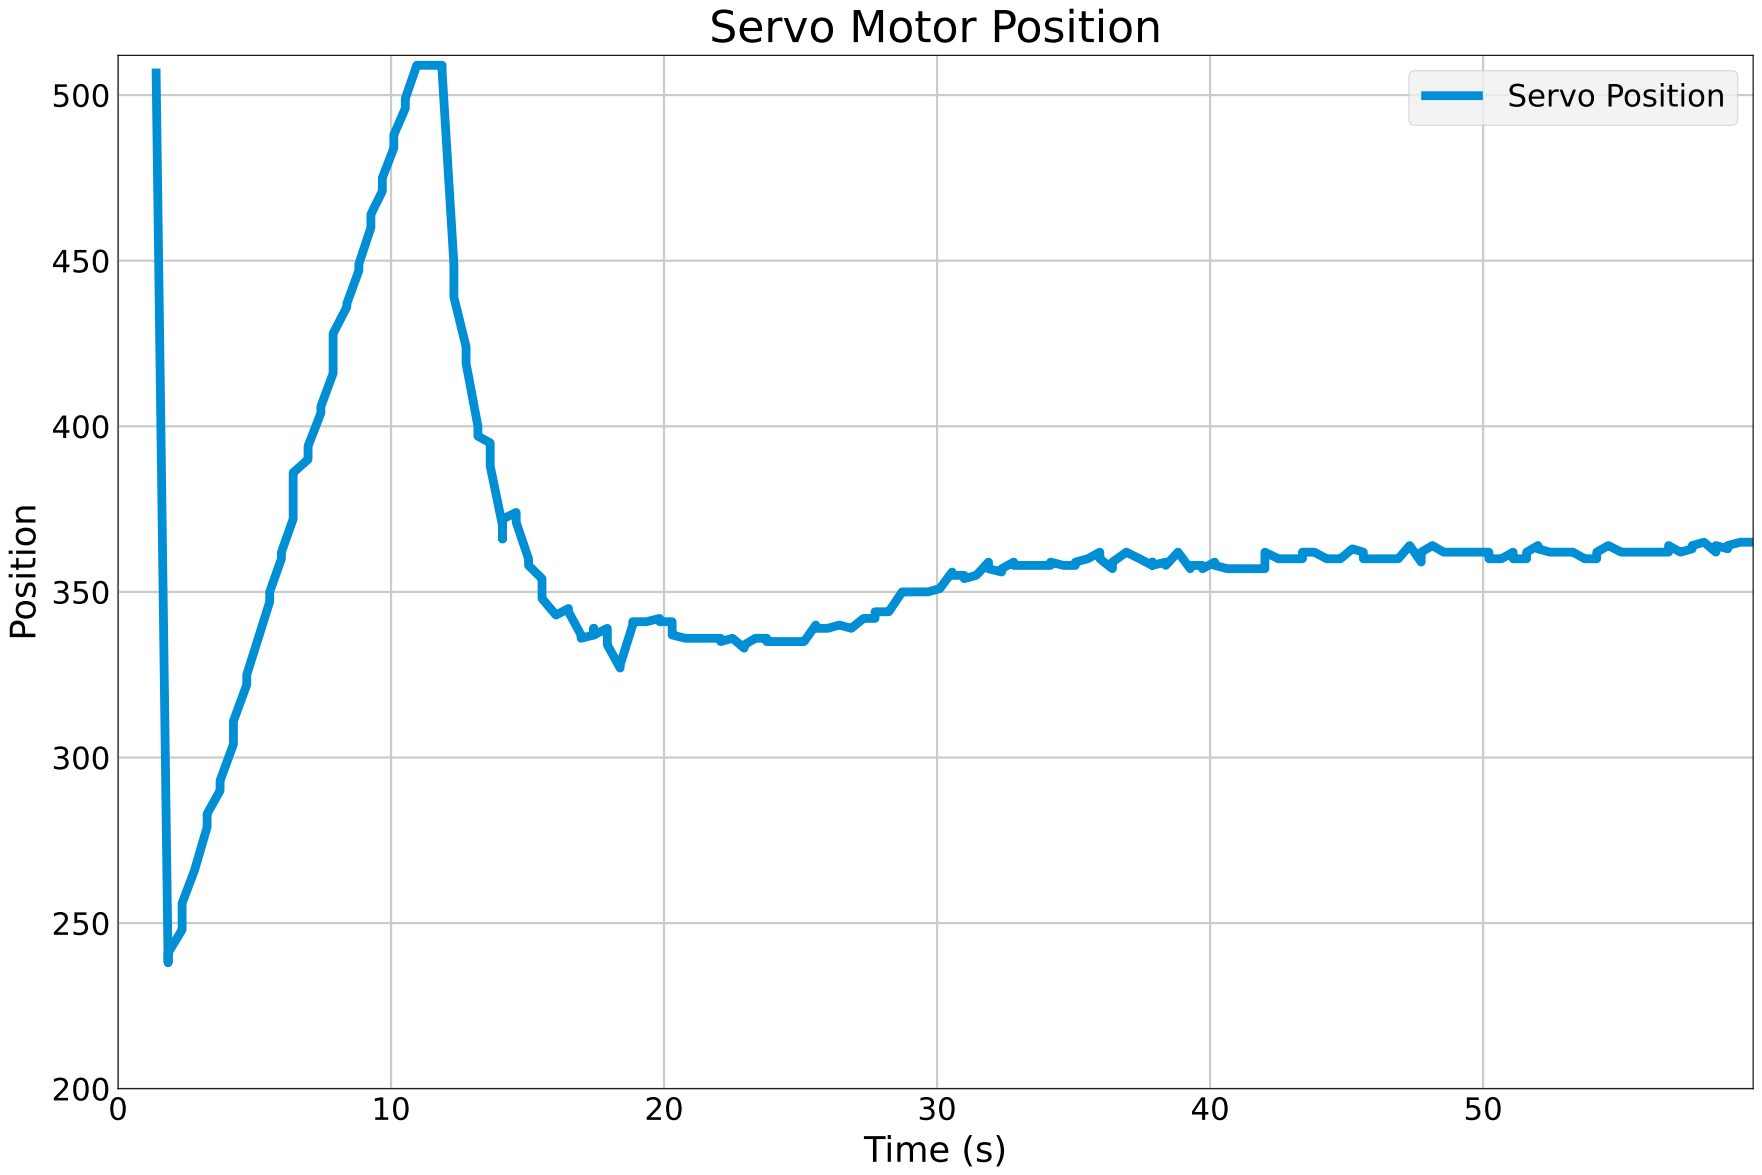
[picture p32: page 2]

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

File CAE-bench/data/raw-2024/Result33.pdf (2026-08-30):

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

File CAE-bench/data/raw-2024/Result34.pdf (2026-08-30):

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

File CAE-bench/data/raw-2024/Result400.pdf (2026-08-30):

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

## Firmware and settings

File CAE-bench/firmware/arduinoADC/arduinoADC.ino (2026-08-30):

#include <ArduinoJson.h>

// System settings
const int baudRate = 19200; // Baud rate of system

// Pins to which the sensors are connected on the system, only pin 2 and 3 of the uno support interrupt
const int pressureInput = A0; // Pin to which the pressure sensor data is connected on the Arduino
const int irInput = 3; // Pin to which the IR sensor data is connected on the Arduino
const int flowSensorPin = 2; // Connect the flow sensor to digital pin 2

// Calibration values of the pressure sensor
const int pressureZero = 98;
const int pressureMax = 800;
const float pressuretransducermaxPSI = 100;
const float psiToBarConversion = 0.0689476;
float pressureValue = 0;

// IR sensor pulse count
volatile int irPulseCount = 0;

// Flow sensor calibration values
volatile int pulseCount = 0;
const float calibrationFactor = 7.5; // Calibration factor for the flow sensor

float flowRate = 0.0;

void setup() {
  Serial.begin(baudRate);       // Initializes serial (USB) connection with baudRate
  pinMode(irInput, INPUT);      // Sets pin mode for IR sensor

  // Set the pin mode for the flow sensor
  pinMode(flowSensorPin, INPUT_PULLUP);

  // Attach interrupt to the flow sensor
  attachInterrupt(digitalPinToInterrupt(flowSensorPin), flowPulseCounter, RISING);

  // Attach interrupt to the IR sensor
  attachInterrupt(digitalPinToInterrupt(irInput), irPulseCounter, FALLING);
}

void loop() {
  // Read the value of the IR sensor and invert the logic
  bool irValue = !digitalRead(irInput);
  int sensorValue = analogRead(pressureInput);

  // Calculate the actual Pressure value
  pressureValue = ((float)sensorValue - pressureZero) * (pressuretransducermaxPSI / (pressureMax - pressureZero));

  // If calculated pressure is lower than 0 set it to 0
  pressureValue = max(pressureValue, 0.0);

  // Calculate pressure in Bar
  float pressureValueInBar = (pressureValue * psiToBarConversion) + 1;

  // Calculate flow rate in L/min
  noInterrupts(); // Disable interrupts while calculating flow rate
  flowRate = (pulseCount / calibrationFactor) * 60;
  pulseCount = 0; // Reset the pulse count
  interrupts(); // Enable interrupts

  // Convert data to JSON file format to be exported to Python
  StaticJsonDocument<200> doc;              // Creates JSON file with max length 200 and type doc
  doc["pressure_bar"] = pressureValueInBar; // Adds data from the pressure sensor to the document
  doc["ir_pulse_count"] = irPulseCount;     // Adds IR pulse count to the document
  doc["flow_rate"] = flowRate;              // Adds data from flow sensor to the document
  doc["irValue"] = irValue;                 // Adds data from IR sensor to the doc
  serializeJson(doc, Serial);               // Sends the JSON file using serial
  Serial.println(); // Add a newline character for better readability

  // Reset IR pulse count after sending data
  irPulseCount = 0;

  // Set delay before initiating next loop
  delay(200); // Reduced delay to 200 milliseconds
}

void flowPulseCounter() {
  pulseCount++;
}

void irPulseCounter() {
  irPulseCount++;
}

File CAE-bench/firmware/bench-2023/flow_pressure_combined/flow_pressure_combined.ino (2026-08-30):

#include "Wire.h" // allows communication over i2c devices
const int pressureInput = A0; // select the analog input pin for the pressure transducer
const int pressureZero = 98; // analog reading of pressure transducer at 0psi
const int pressureMax = 800; // analog reading of pressure transducer at 100psi
const int pressuretransducermaxPSI = 100; // psi value of transducer being used
const int baudRate = 9600; // constant integer to set the baud rate for serial monitor
const int sensorreadDelay = 250; // constant integer to set the sensor read delay in milliseconds

volatile int flow_frequency; // Measures flow sensor pulses
unsigned int l_hour; // Calculated litres/hour
unsigned char flowsensor = 2; // Sensor Input
unsigned long currentTime;
unsigned long cloopTime;

float pressureValue = 0; // variable to store the value coming from the pressure transducer

void flow () // Interrupt function
{
  flow_frequency++;
}

void setup()
{
  pinMode(flowsensor, INPUT);
  digitalWrite(flowsensor, HIGH); // Optional Internal Pull-Up
  Serial.begin(baudRate); // initializes serial communication at set baud rate bits per second
  attachInterrupt(0, flow, RISING); // Setup Interrupt
  sei(); // Enable interrupts
  currentTime = millis();
  cloopTime = currentTime;
}

void loop()
{
  currentTime = millis();
  
  // Every second, calculate and print litres/hour
  if(currentTime >= (cloopTime + 1000))
  {
    cloopTime = currentTime; // Updates cloopTime
    
    // Pulse frequency (Hz) = 7.5Q, Q is flow rate in L/min.
    l_hour = (flow_frequency * 60 / 7.5); // (Pulse frequency x 60 min) / 7.5Q = flowrate in L/hour
    flow_frequency = 0; // Reset Counter
    
    pressureValue = analogRead(pressureInput); // reads value from input pin and assigns to variable
    pressureValue = ((pressureValue-pressureZero)*pressuretransducermaxPSI)/(pressureMax-pressureZero); // conversion equation to convert analog reading to psi
    
    Serial.print("Flow Rate: ");
    Serial.print(l_hour, DEC); // Print litres/hour
    Serial.println(" L/hour");
    
    Serial.print("Pressure: ");
    Serial.print(pressureValue, 1); // prints value from previous line to serial
    Serial.println(" psi");
    
    delay(sensorreadDelay); // delay in milliseconds between read values
  }
}

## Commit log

2026-08-30 Compressed-air systems: bench replication package and port-Hamiltonian control
    [CAE(1).SLDPRT, CAE_bench_corrected_data.xlsx, CAEconnect.SLDPRT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]
2026-08-30 Add Wankel engine, pneumatic and torque-rig CAD, and 2023 bench firmware
    [Casing1-8.SLDPRT, Casing1-8.STL, Engine mounting base.stl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]
2026-08-30 Update docs for the recovered CAD and firmware; refile three misplaced files
